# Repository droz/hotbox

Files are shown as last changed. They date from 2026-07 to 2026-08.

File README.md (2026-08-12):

# Baked and Happy Hot-Box

Solar oven project with motorized mirrors, a Raspberry Pi supervisor, and two separate simulation stacks.

## System Overview

The oven body keeps its original controller panel, but the heating element relay is repurposed as a demand signal for the solar concentrator. When the oven wants power, a set of motorized mirrors aims reflected sunlight at the absorber on the back of the oven. When the oven does not want power, the mirrors park toward a safe sky target.

Each mirror is a faceted spherical mirror mounted on an alt-azimuth mount:

- angles use the astronomical convention: elevation `0°` = horizon / `90°` = zenith;
  azimuth `0°` = north, `90°` = east (clockwise from north)
- body → world rotation is `R_z(−az) @ R_x(el − 90°)` (identity / face-up at `(0, 90)`)
- each mirror has a local mount frame `Fm`
- the oven absorber center `O` is the origin of the world frame `Fw`

The world frame used by the software is:

- `X`: east
- `Y`: north
- `Z`: up

## Hardware Architecture

### Mirror Controller

Each mirror has its own Arduino Nano ESP32 board. The board controls:

- two brushed DC motors through DRV8871 drivers
- one quadrature encoder per motor
- one hall sensor per axis for homing/reference

The mirror controller communicates with the main controller in two ways:

- **CAN bus** for normal operation in the final system
- **USB serial** for debugging, bench bring-up, and testing without the CAN bus

Pin mappings are documented in `electrical/pinouts.txt`.

### Main Controller

The main controller is a Raspberry Pi with:

- an MCP2515 CAN hat on SPI
- a GPIO input that reads the oven's original heat-demand relay state
- a GY-NEO6MV2 NEO-6M GPS module for time and location

The Pi:

- computes the sun location from GPS data using `pvlib`
- converts the sun position into a world-frame vector
- computes where each mirror should point
- sends commands to each mirror node
- serves a small web UI for monitoring, manual control, and calibration

## Software Architecture

## `firmware/`

Arduino-first mirror-node firmware with the same high-level command set over CAN and USB serial.

Responsibilities:

- homing from hall sensors
- encoder counting
- motor PWM and direction control
- closed-loop axis tracking with acceleration limiting
- stall/fault reporting
- mirror status reporting

The current scaffold is intentionally thin and is meant to grow around proven libraries rather than custom low-level drivers.

## `controller/`

Python package for the Raspberry Pi runtime.

Responsibilities:

- GPS NMEA parsing for the NEO-6M (with site fallback when no fix)
- sun vector calculation with `pvlib`
- mirror discovery and supervision
- transport abstraction for `CAN` and `USB serial`
- target generation for active tracking or safe parking
- calibration file loading/saving
- FastAPI server plus a lightweight Three.js web page
- current pose vs commanded target geometry overlay in the web UI

Current module split:

- `hotbox_controller/gps.py`
- `hotbox_controller/sun.py`
- `hotbox_controller/scene.py`
- `hotbox_controller/transport.py`
- `hotbox_controller/mirror_fleet.py`
- `hotbox_controller/tracking.py`
- `hotbox_controller/calibration.py`
- `hotbox_controller/app.py`

## `sim_in_the_loop/`

Fast SITL for controller and firmware development: real firmware C-in-the-loop
(`axis`/`protocol` as per-node native libraries) plus a Python plant
(motors/encoders/halls) and the same JSON protocol as USB.

Purpose:

- run the same control code as the ESP32 on a laptop
- simulate motors, encoders, and hall sensors
- visualize simplified aiming geometry
- debug calibration and mirror pointing

This simulation intentionally uses:

- one representative ray per facet center
- no occlusion model
- simulator-owned "true" calibration values

Its goal is software integration and geometry debugging, not high-fidelity thermal/power prediction.

## `sim_full_raytrace/`

Renamed version of the original exploratory optical simulator. This remains the place for:

- many-ray optical studies
- occlusion effects
- delivered power estimation
- geometry experiments that need more fidelity than the in-the-loop simulator

Plant geometry (site, absorber, facet grid, fleet mounts) is loaded from `config/system.yaml`
via `hotbox_shared`, same as the controller and SITL.
## Tracking And Control Flow

1. The Pi boots and starts the controller service.
2. GPS provides current UTC time and site coordinates.
3. The controller loads saved calibration data.
4. Mirror nodes are discovered over the configured transport (`CAN` or `USB serial`).
5. Mirrors are homed if needed.
6. The controller computes the current sun vector from `pvlib`.
7. If the oven requests heat, mirrors track the absorber.
8. If the oven does not request heat, mirrors park to a safe sky direction.

## Calibration

Per mirror, the known geometric values are:

- distance `|OA_n|`
- mirror offset `d = |A_nM_n|`
- mirror focal length

The unknowns to calibrate are:

- bearing of `OA_n` relative to north
- height difference between `O` and `A_n`
- homed azimuth offset
- homed elevation offset

Calibration flow:

1. Home the mirror.
2. Jog until the center facet points directly at `O`.
3. Jog until the sun is focused on `O`.
4. Save the solved calibration values to disk.

The controller package already includes calibration file load/save support. The numerical solve and guided routine still need to be filled out in more detail as hardware data becomes available.

## Library Strategy

Prefer existing libraries where they fit:

- firmware: `ESP32Encoder`, `PID`, PlatformIO-managed deps; CAN via ESP32-S3 TWAI
- controller: `pvlib`, `python-can`, `pyserial`, `FastAPI`, `numpy`, `scipy`, `PyYAML`
- UI: `Three.js`

Custom code should stay focused on:

- project-specific geometry
- transport-neutral mirror protocol
- calibration math
- plant models for SITL (encoders/halls/PWM), with firmware C-in-the-loop

## Repository Layout

- `config/` — shared plant constants (`system.yaml`) and calibration files
- `shared/` — Python package that loads those shared constants
- `controller/` — Raspberry Pi controller package
- `electrical/` — pinouts and electronics notes
- `firmware/` — mirror-node firmware
- `mechanical/` — CAD and printable parts
- `sim_full_raytrace/` — high-fidelity optical simulator
- `sim_in_the_loop/` — fast integration simulator

## Shared plant constants

Geometry and plant constants live in one place:

```text
config/system.yaml
```

Loaded by:

```python
from hotbox_shared import load_system_constants
system = load_system_constants()
```

This includes:

- default site lat/lon/altitude
- absorber size and height
- mirror facet grid (`nx`/`ny`), tile size, pitch
- mount offset `d`, sphere radius / focal length
- fleet mount bearings (relative to oven/absorber normal) and `|OA|` design values

Generate the firmware C header from the same file:

```bash
cd shared && uv run hotbox-gen-firmware-geometry
```

That writes `firmware/include/hotbox_geometry.h`.

## Development

Python packages use `uv`.

Examples:

```bash
cd controller && uv run hotbox-controller
cd sim_in_the_loop && uv run hotbox-sim-in-the-loop
# then open http://127.0.0.1:8000/
cd sim_full_raytrace && uv run hotbox-sim-full-raytrace
```

`hotbox-sim-in-the-loop` starts a continuous simulation and the controller web UI.
Use `--batch-seconds N` for a short headless run.

### Transports

The controller supports three mirror transports:

- `usb` — JSON lines over USB serial (`pyserial`); default for bench bring-up
- `can` — compact binary frames over SocketCAN (`python-can`); typical on a Pi in the field
- `sim` — in-process firmware-CIL mirror nodes (used by `sim_in_the_loop/`)

Override transport with `HOTBOX_TRANSPORT=usb|can|sim` (default `usb`).

USB port mapping:

- **One** Arduino Nano ESP32 plugged in → auto-discovered by USB VID/PID (`2341:0070`) and mapped to **node 0**
- **Multiple** boards → set an explicit map (VID/PID alone cannot tell which board is which node):

```bash
export HOTBOX_USB_PORTS='0:/dev/cu.usbmodem1101,1:/dev/ttyACM1'
```

Paths look like `/dev/cu.usbmodem*` on macOS and `/dev/ttyACM*` on Linux.

### Flash firmware and test a real board (not simulation)

Works the same on a Mac (USB bench) or a Raspberry Pi.

1. **Plug in** the Nano ESP32 over USB. Unplug other Nano ESP32 boards first for single-board bring-up.

2. **Flash** firmware for the matching node id (single-board auto-discovery expects **0**):

```bash
cd firmware
uv run hotbox-firmware-upload --node-id 0
# optional: --port /dev/cu.usbmodem1101   # or /dev/ttyACM0 on Linux
```

Upload always builds that node first. For a second board, flash `--node-id 1`, leave both plugged in, and set `HOTBOX_USB_PORTS` as above.

3. **Start the controller** against real USB (not `sim_in_the_loop`):

```bash
cd controller
# optional: export HOTBOX_TRANSPORT=usb
# optional: export HOTBOX_USB_PORTS='0:/dev/ttyACM0'
uv run hotbox-controller
```

Open [http://127.0.0.1:8000/](http://127.0.0.1:8000/). You should see mirror **M0** with current pose (blue) and commanded target (yellow).

4. **Smoke-test from the UI**

- Select the **M0** tab.
- Put the mirror in **Raw** so Track/Park do not overwrite your wire commands.
- Expand **Protocol** → send `get_status` and confirm a status reply in the log.
- Prefer **Home** once (or Protocol `home`) before commanding large moves.
- Try Protocol `set_target` with small angles, or switch to **Jog** and nudge with the stick.
- Use **Park** / **Track** only when you intend the supervisor to drive targets (Track also follows heat-demand / sun logic).

On a Pi with CAN instead of USB serial:

```bash
export HOTBOX_TRANSPORT=can
# nodes are addressed by CAN id; plug USB only if you still need it for programming
cd controller && uv run hotbox-controller
```

Firmware build/upload helpers:

```bash
cd firmware
uv run hotbox-firmware-build --node-id 0
uv run hotbox-firmware-upload --node-id 1 --port /dev/ttyACM0
```

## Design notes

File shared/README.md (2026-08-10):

# hotbox-shared

Shared plant constants and mirror pointing geometry for:

- `controller/`
- `sim_in_the_loop/`
- `sim_full_raytrace/`
- firmware (via generated C header)

## Source of truth

Edit the repo-level file:

```text
config/system.yaml
```

Then load it in Python:

```python
from hotbox_shared import load_system_constants

system = load_system_constants()
print(system.default_site.latitude_deg)
print(system.default_site.timezone_id)
print(system.absorber.center_height_m)
print(system.mirror.grid_nx, system.mirror.grid_ny)
print(system.control.solve_for_mount_offset)
```

## Site time and location

Never use the computer's local timezone. Civil-day work and plots use
`default_site.timezone_id` from `config/system.yaml`. Live time prefers GPS UTC when
available, otherwise `utc_now()`.

```python
from hotbox_shared import (
    SitePose,
    as_site_local,
    ensure_utc,
    format_site_local,
    load_system_constants,
    local_times_sunrise_to_sunset,
    site_local_datetime,
    utc_now,
)

site = SitePose.from_constants(load_system_constants().default_site)
when = site_local_datetime(site, 2026, 9, 7, 14, 0, 0)  # 14:00 at the plant
times, sunrise, sunset = local_times_sunrise_to_sunset(
    site, year=2026, month=9, day=7, step_minutes=20
)
print(format_site_local(when, site))
print(ensure_utc(when))  # physics / pvlib
```

| Symbol | Role |
|---|---|
| `SitePose` | lat/lon/alt + IANA `timezone_id` |
| `site_local_datetime` | Build aware civil time at the site |
| `as_site_local` / `format_site_local` | Convert / print in site TZ |
| `ensure_utc` | Aware → UTC; **raises** on naive (no host-TZ guess) |
| `utc_now` | Host clock as UTC (fallback when GPS unavailable) |
| `local_times_sunrise_to_sunset` | Site-local samples from SPA sunrise→sunset |

## Mirror pointing

Both the live controller and the full raytrace simulation use the same aiming solver in
`hotbox_shared.aiming`. This is the single source of truth for deciding where each alt-az
mount should point.

### Quick start

```python
import numpy as np
from hotbox_shared import MirrorGridSpec, evaluate_center_ray, solve_tracking_for_grid

grid = MirrorGridSpec(
    grid_nx=3,
    grid_ny=5,
    pitch_m=0.26035,
    radius_of_curvature_m=5.5,
    mount_offset_d_m=0.1,
)

# Unit vector from the sun toward the plant (ENU world frame).
sun_toward_scene = -sun_vector_from_pvlib
mount = np.array([0.0, 2.5, 1.0])
target = np.array([0.0, 0.0, 1.0])  # absorber center

angles = solve_tracking_for_grid(
    sun_direction_toward_scene=sun_toward_scene,
    mount_world=mount,
    target_world=target,
    grid=grid,
    solve_for_mount_offset=True,  # also controlled by control.solve_for_mount_offset in YAML
)

# Forward model: where does the center ray go?
ray = evaluate_center_ray(
    sun_direction_toward_scene=sun_toward_scene,
    mount_world=mount,
    azimuth_deg=angles.azimuth_deg,
    elevation_deg=angles.elevation_deg,
    mount_offset_d_m=grid.mount_offset_d_m,
    pivot_facet_normal_body=grid.pivot_normal_body(),
)
print(angles.azimuth_deg, angles.elevation_deg)
print("miss_m", ray.miss_m(target))
print("impact on absorber plane", ray.impact_on_plane(target, np.array([0.0, 1.0, 0.0])))
```

### Algorithm

1. **Bisector seed** — flat heliostat at the mount pivot (ignores `mount_offset_d_m`).
2. **Offset refine** (optional) — `scipy.optimize.least_squares` nudges `(az, el)` so the
   **center facet** reflected ray aims at the absorber. Forward model:
   `evaluate_center_ray`.

Toggle refinement with `control.solve_for_mount_offset` in `config/system.yaml`
(set `false` to keep the bisector seed only).

### API reference

| Symbol | Role |
|---|---|
| `solve_tracking` / `solve_tracking_for_grid` | **Primary** aiming API (seed + optional refine) |
| `evaluate_center_ray` / `CenterRay` | Forward geometry: facet pose, reflected ray, miss / plane impact |
| `solve_bisector_tracking` | Closed-form pivot bisector seed only |
| `MountAngles` | Result: `azimuth_deg`, `elevation_deg` |
| `MirrorGridSpec` | Facet grid + `mount_offset_d_m` |
| `pivot_facet_center_world` | `mount + R @ (0,0,d)` |
| `mount_rotation_matrix` | Body → world rotation `R_z(−az) @ R_x(el − 90°)` (astro az/el) |

### Frames

Right-handed ENU world frame: **+x east**, **+y north**, **+z up**. Mount body frame
matches world at `(azimuth, elevation) = (0, 90)`. Center facet at `(0, 0, mount_offset_d_m)`
in body coordinates.

## Firmware header

Generate a C header from the same YAML:

```bash
cd shared
uv run hotbox-gen-firmware-geometry
```

This writes `firmware/include/hotbox_geometry.h`.

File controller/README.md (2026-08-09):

# hotbox controller

Main Python runtime for the Raspberry Pi:

- reads GPS time/location
- computes the sun vector with `pvlib`
- supervises mirror nodes over CAN or USB serial
- manages calibration files
- serves a small FastAPI + Three.js UI

Run locally with:

```bash
uv run hotbox-controller
```

Then open `http://127.0.0.1:8000/`.

**USB bring-up:** with a single Arduino Nano ESP32 connected, the board is auto-discovered
(VID/PID `2341:0070`) and mapped to node 0. For multiple boards, set
`HOTBOX_USB_PORTS=0:/dev/...,1:/dev/...`. See the root README section
“Flash firmware and test a real board”.

**Simulation:** use `sim_in_the_loop` (`HOTBOX_TRANSPORT=sim`) instead of this package alone.

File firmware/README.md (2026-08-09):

# hotbox firmware

Arduino-first mirror controller for the Arduino Nano ESP32.

Goals:

- same high-level command protocol over CAN and USB serial
- brushed DC motor control through DRV8871
- quadrature encoder + hall homing
- host-shim friendly structure for simulation

Build / flash with `uv` (installs PlatformIO into this package env).
Each mirror has its own build env, and upload always builds that node first:

```bash
cd firmware
uv run hotbox-firmware-build --node-id 0
uv run hotbox-firmware-upload --node-id 1
# optional: uv run hotbox-firmware-upload --node-id 1 --port /dev/cu.usbmodem1101
```

`--node-id` must be `0`, `1`, or `2` (matches `config/system.yaml` mounts).

Or call PlatformIO directly:

```bash
pio run -e nano_esp32_node0
pio run -t upload -e nano_esp32_node1
```

The firmware implements:

- brushed-axis control with `ESP32Encoder` + `PID_v1`
- hall-sensor homing
- position servo (`set_target`); host integrates jog rates into targets
- status modes: `idle` | `homing` | `position` | `fault`
- USB serial JSON protocol and ESP32-S3 TWAI (CAN) binary protocol
- TWAI soft-fails without a transceiver so USB bench bring-up still works

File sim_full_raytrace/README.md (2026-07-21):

# hotbox full raytrace sim

Vectorized optical raytrace for the Hot-Box flat-mirror solar oven (rigid facet grid on
alt–az mounts). Plant geometry comes from the shared repo config; sim-only knobs stay in
`src/main.py`.

## Shared plant constants

Edit:

```text
config/system.yaml
```

Loaded via:

```python
from hotbox_shared import load_system_constants
```

This drives site lat/lon/altitude, absorber size, facet grid, sphere radius, mount offset
`d`, and fleet mount bearings relative to the oven/absorber normal (same source as controller
and SITL).

## Run with uv

```bash
uv run hotbox-sim-full-raytrace
```

The script prints power statistics and opens Plotly figures:

- 3D scene (ground, absorber, mirror tiles, incoming and reflected rays)
- Spot pattern on absorber plane
- Delivered power vs local time (sunrise–sunset on the configured day)

Sim-only options (samples, day-curve dates, visualization density) live in `src/main.py`.
Incoming ray power uses **pvlib** clear-sky DNI (Ineichen) at the simulation time for the
configured site.

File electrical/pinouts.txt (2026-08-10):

MOTOR CONNECTOR
---------------

NAME         | COLOR  | CIRCULAR_PIN  | JST_PIN 
-------------+--------+---------------+---------
MOTOR+       | RED    | 1             | 2-1  
MOTOR-       | BLACK  | 2             | 2-2
ENC/HALL_GND | GREY   | 7             | 6-1
ENC_VCC      | BLUE   | 6             | 6-2
ENC_A        | YELLOW | 3             | 6-4
ENC_B        | WHITE  | 4             | 6-5
HALL_VCC     | BROWN  | 8             | 6-3
HALL_OUT     | GREEN  | 5             | 6-6

INTERFACE CONNECTOR
-------------------

NAME         | COLOR  | JST_PIN
-------------+--------+----------
GND          | BLACK  | 1
VCC_12V      | RED    | 2
CAN_H        | YELLOW | 3
CAN_L        | GREEN  | 4

Firmware pin *roles* (including encoder A/B sense) live in config/system.yaml
under `pins:` and are baked into firmware via `uv run hotbox-gen-firmware-geometry`.
Swap elevation_enc_a/b or azimuth_enc_a/b there to invert quadrature direction.

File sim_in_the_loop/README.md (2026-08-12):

# hotbox sim in the loop

Controller + **firmware C-in-the-loop** (real `axis`/`protocol` C++) + Python plant,
talking the same JSON protocol as USB, with a live web UI.

## Prerequisites

Native CIL libraries (autobuild on first run, or explicitly):

```bash
cd firmware/native && make
```

This produces `libfirmware_cil_node{0,1,2}.dylib` (macOS) or `.so` (Linux) — one
library per mirror so multi-node sims do not share HAL state.

## Live interactive mode (default)

```bash
uv run hotbox-sim-in-the-loop
```

Then open:

```text
http://127.0.0.1:8000/
```

Or from another device on the same network (server binds to all interfaces by default):

```text
http://<your-lan-ip>:8000/
```

The page shows:

- current reported pose (blue)
- firmware position setpoint / target (yellow)
- GPS / sun / mirror status
- Home, Park, Auto, and jog controls

Optional flags:

```bash
uv run hotbox-sim-in-the-loop --host 127.0.0.1 --port 8000
```

Use `--host 127.0.0.1` if you want localhost-only access.

## Headless batch mode

Useful for smoke tests:

```bash
uv run hotbox-sim-in-the-loop --batch-seconds 3
```

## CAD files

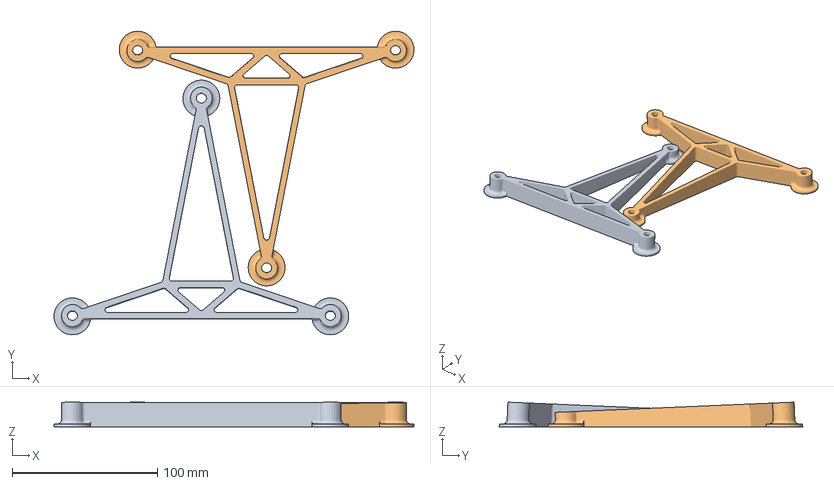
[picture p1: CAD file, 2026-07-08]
mechanical/3D Printed Mirror Support_0,1.3mf
248.2 x 209.2 x 17.1 mm

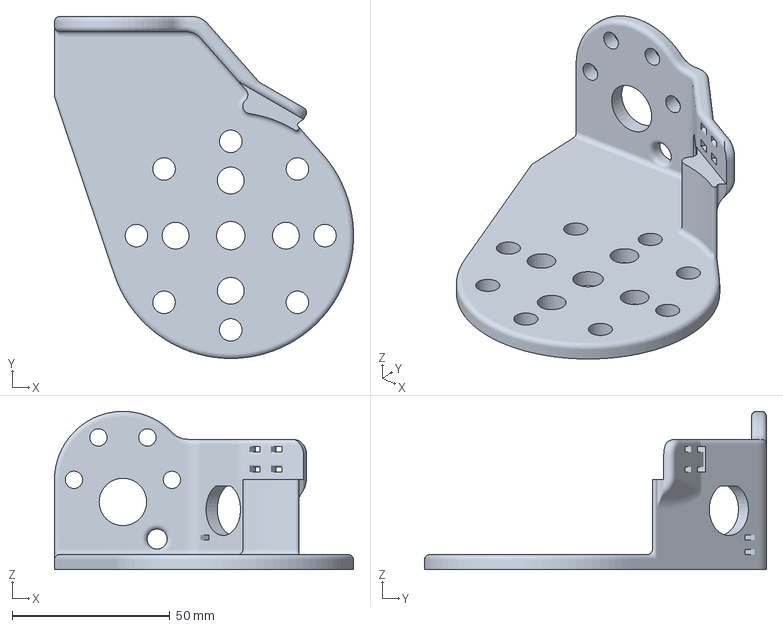
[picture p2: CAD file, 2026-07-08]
mechanical/3D Printed Motor Support.3mf
94.7 x 108.3 x 50.1 mm

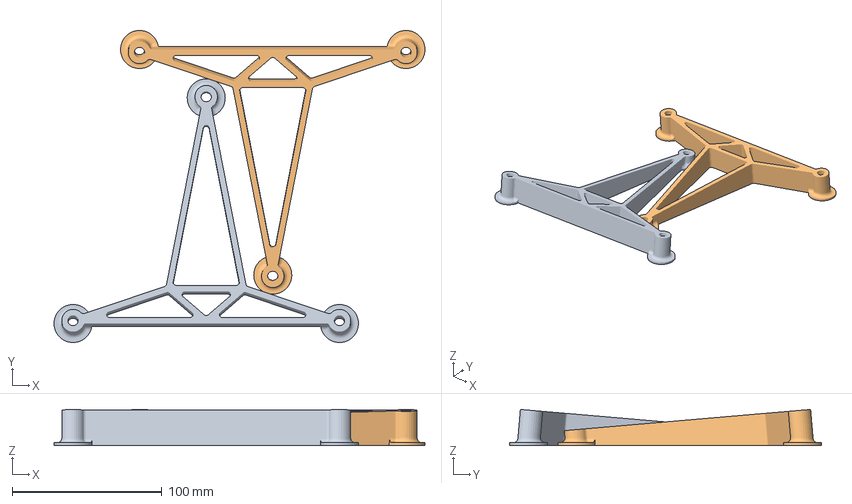
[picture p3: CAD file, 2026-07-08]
mechanical/3D Printed Mirror Support_0,2.3mf
247.6 x 208.2 x 24.1 mm

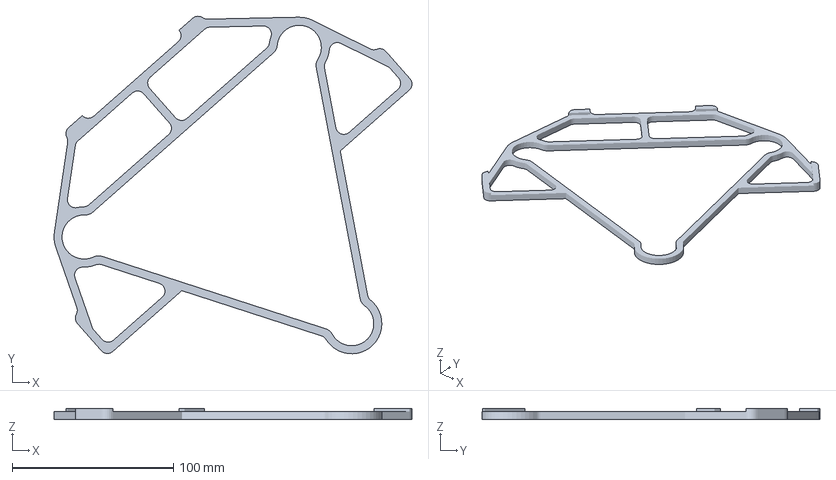
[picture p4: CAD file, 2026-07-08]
mechanical/3D Printed Mirror Support_jig.3mf
222.0 x 209.3 x 7.00 mm

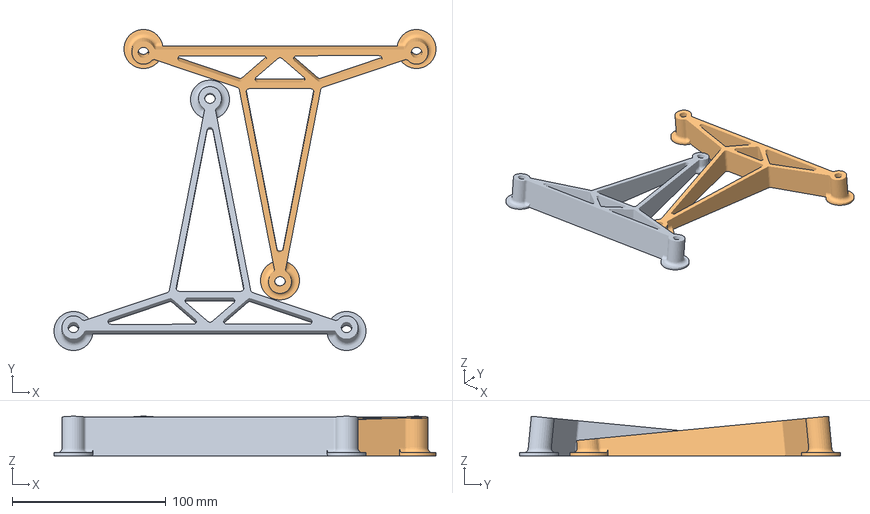
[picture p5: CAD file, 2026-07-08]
mechanical/3D Printed Mirror Support_1,2.3mf
248.8 x 209.0 x 25.8 mm

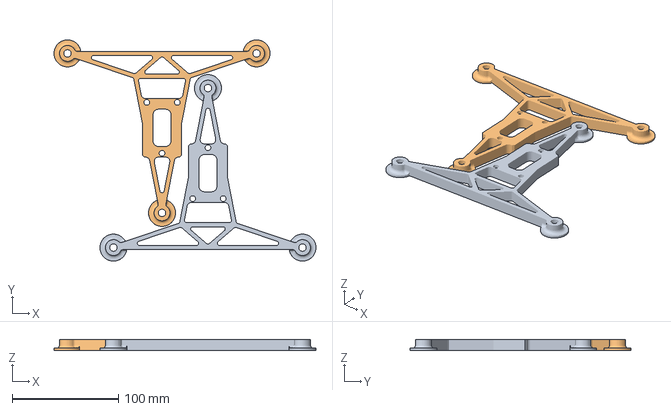
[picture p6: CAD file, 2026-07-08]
mechanical/3D Printed Mirror Support_0,0.3mf
246.4 x 208.0 x 10.0 mm

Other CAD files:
mechanical/3D Printed Mirror Support_1,1.3mf

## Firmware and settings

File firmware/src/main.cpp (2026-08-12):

#include <Arduino.h>

#include "axis.h"
#include "can_bus.h"
#include "config.h"
#include "protocol.h"

#include <cstring>

hotbox::MirrorMount g_mount;
hotbox::ProtocolHandler g_protocol(&g_mount);
hotbox::CanBus g_can(&g_protocol);

namespace {

constexpr size_t kSerialLineMax = 512;
constexpr int kSerialBytesPerLoop = 96;

}  // namespace

void setup() {
  Serial.begin(115200);
  // USB CDC: wait briefly for the host to open the port after reset-on-open.
  const unsigned long wait_start = millis();
  while (!Serial && (millis() - wait_start) < 3000) {
    delay(10);
  }
  delay(200);
  g_mount.begin();
  g_can.begin();  // Soft-fails without a transceiver; USB still works.
  Serial.print("{\"hotbox\":\"mirror_firmware\",\"transport\":\"usb\",\"node_id\":");
  Serial.print(HOTBOX_NODE_ID);
  Serial.print(",\"az_hall\":");
  Serial.print(g_mount.azimuthHallTriggered() ? "true" : "false");
  Serial.print(",\"el_hall\":");
  Serial.print(g_mount.elevationHallTriggered() ? "true" : "false");
  Serial.println("}");
}

void loop() {
  static char line_buf[kSerialLineMax];
  static size_t line_len = 0;
  static unsigned long last_update_ms = 0;
  static bool was_homing = false;
  const unsigned long now_ms = millis();
  const float dt_s = (now_ms - last_update_ms) / 1000.0f;

  // Control first: never let USB RX/TX starve the motor loop (runaway PWM).
  if (last_update_ms == 0 || dt_s >= hotbox::kControlPeriodS) {
    const float step_dt = (last_update_ms == 0) ? hotbox::kControlPeriodS : dt_s;
    g_mount.update(step_dt);
    last_update_ms = now_ms;

    const bool homing = std::strcmp(g_mount.modeText(), "homing") == 0;
    if (was_homing && !homing) {
      // Homing finished (success → idle/homed, or fault). Push status so the
      // host does not have to wait for the next poll.
      g_protocol.emitStatus();
    }
    was_homing = homing;
  }

  int budget = kSerialBytesPerLoop;
  while (budget-- > 0 && Serial.available() > 0) {
    const char ch = static_cast<char>(Serial.read());
    if (ch == '\n' || ch == '\r') {
      if (line_len > 0) {
        line_buf[line_len] = '\0';
        g_protocol.handleLine(String(line_buf));
        line_len = 0;
      }
    } else if (line_len + 1 < kSerialLineMax) {
      line_buf[line_len++] = ch;
    } else {
      // Overflow / garbage: drop the line rather than grow forever.
      line_len = 0;
    }
  }

  g_can.poll();
}

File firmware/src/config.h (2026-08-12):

#pragma once

#include <Arduino.h>
#include "hotbox_geometry.h"

namespace hotbox {

// ── Pin assignments (from config/system.yaml via hotbox_geometry.h) ───────────
constexpr int kCanTxPin = HOTBOX_PIN_CAN_TX;
constexpr int kCanRxPin = HOTBOX_PIN_CAN_RX;

constexpr int kVertMotorP = HOTBOX_PIN_ELEVATION_MOTOR_P;
constexpr int kVertMotorM = HOTBOX_PIN_ELEVATION_MOTOR_M;
constexpr int kVertEncA = HOTBOX_PIN_ELEVATION_ENC_A;
constexpr int kVertEncB = HOTBOX_PIN_ELEVATION_ENC_B;
constexpr int kVertHall = HOTBOX_PIN_ELEVATION_HALL;

constexpr int kHorizMotorP = HOTBOX_PIN_AZIMUTH_MOTOR_P;
constexpr int kHorizMotorM = HOTBOX_PIN_AZIMUTH_MOTOR_M;
constexpr int kHorizEncA = HOTBOX_PIN_AZIMUTH_ENC_A;
constexpr int kHorizEncB = HOTBOX_PIN_AZIMUTH_ENC_B;
constexpr int kHorizHall = HOTBOX_PIN_AZIMUTH_HALL;

// H-bridge PWM carrier (Arduino-ESP32 default is 1 kHz; 20 kHz is above hearing).
constexpr int kMotorPwmHz = HOTBOX_MOTOR_PWM_HZ;

#ifndef HOTBOX_NODE_ID
#define HOTBOX_NODE_ID 0
#endif

// ESP32Encoder / TWAI take Espressif GPIO numbers. On Nano ESP32 the Arduino
// D# labels are remapped (D5 → GPIO 8, etc.), so convert before driving
// peripherals that bypass the Arduino pin API.
#if defined(NATIVE_CIL)
inline int pinToGpio(int arduino_pin) { return arduino_pin; }
#else
inline int pinToGpio(int arduino_pin) {
  return static_cast<int>(digitalPinToGPIONumber(static_cast<int8_t>(arduino_pin)));
}
#endif

// ── Actuator constants (generated from config/system.yaml) ───────────────────
// Regenerate with: uv run hotbox-gen-firmware-geometry
constexpr float kControlPeriodS         = HOTBOX_CONTROL_PERIOD_S;
constexpr float kMaxVelocityDegS        = HOTBOX_MAX_VELOCITY_DEG_S;
constexpr float kMaxAccelDegS2          = HOTBOX_MAX_ACCEL_DEG_S2;
constexpr float kHomingVelocityDegS     = HOTBOX_HOMING_VELOCITY_DEG_S;
constexpr float kHomingClearDistanceDeg = HOTBOX_HOMING_CLEAR_DISTANCE_DEG;
/** Post-home azimuth relative to oven-facing (same frame as kAzimuthMin/MaxDeg). */
constexpr float kHomeAzimuthDeg         = HOTBOX_HOME_AZIMUTH_DEG;
/** Post-home elevation absolute (0° = horizon, 90° = zenith). */
constexpr float kHomeElevationDeg       = HOTBOX_HOME_ELEVATION_DEG;
/** Encoder-space seek sign for azimuth/elevation (+1 or -1). Leave uses opposite. */
constexpr float kHomingDirectionAzimuth =
    (HOTBOX_HOMING_DIRECTION_AZIMUTH < 0) ? -1.0f : 1.0f;
constexpr float kHomingDirectionElevation =
    (HOTBOX_HOMING_DIRECTION_ELEVATION < 0) ? -1.0f : 1.0f;
/** Expected hall magnet window width [°] (edge-to-edge). */
constexpr float kHallWindowWidthDeg = HOTBOX_HALL_WINDOW_WIDTH_DEG;
/** Allowed |measured − expected| hall width after home [°]. */
constexpr float kHallWindowToleranceDeg = HOTBOX_HALL_WINDOW_TOLERANCE_DEG;
constexpr float kTicksPerDegree         = HOTBOX_TICKS_PER_DEGREE;
constexpr float kPidKp                  = HOTBOX_PID_KP;
constexpr float kPidKi                  = HOTBOX_PID_KI;
constexpr float kPidKd                  = HOTBOX_PID_KD;
constexpr float kPidVelocityKp          = HOTBOX_PID_VELOCITY_KP;
constexpr float kPidVelocityKi          = HOTBOX_PID_VELOCITY_KI;
constexpr float kPidVelocityKd          = HOTBOX_PID_VELOCITY_KD;
constexpr float kPidIntegralLimit       = HOTBOX_PID_INTEGRAL_LIMIT;
constexpr float kPwmDeadband            = HOTBOX_PWM_DEADBAND;
constexpr float kPositionDeadbandDeg    = HOTBOX_POSITION_DEADBAND_DEG;
constexpr float kStallVelocityThreshDegS = HOTBOX_STALL_VELOCITY_THRESHOLD_DEG_S;
constexpr float kStallTimeoutS          = HOTBOX_STALL_TIMEOUT_S;
/** If no set_velocity refresh arrives while in Velocity mode, coast (host lost / USB stall). */
constexpr float kVelocityCommandTimeoutS = 0.30f;

// Joint limits (from config/system.yaml). Azimuth is joint-relative to oven-facing.
constexpr float kElevationMinDeg = HOTBOX_ELEVATION_MIN_DEG;
constexpr float kElevationMaxDeg = HOTBOX_ELEVATION_MAX_DEG;
constexpr float kAzimuthMinDeg = HOTBOX_AZIMUTH_MIN_DEG;
constexpr float kAzimuthMaxDeg = HOTBOX_AZIMUTH_MAX_DEG;

}  // namespace hotbox

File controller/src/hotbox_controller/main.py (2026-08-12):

from __future__ import annotations

import uvicorn

from .app import ControllerApplication


def main() -> None:
    app = ControllerApplication()
    app.startup()
    # Closed-loop Track/Park (and jog rate streaming) need a periodic tick.
    # SITL runs control_tick from its physics thread instead.
    app.start_control_loop()
    try:
        uvicorn.run(app.fastapi, host=app.config.web_host, port=app.config.web_port)
    finally:
        app.stop_control_loop()


if __name__ == "__main__":
    main()

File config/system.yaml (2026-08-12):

# Hot-Box plant / geometry constants
# Shared by controller, sim_in_the_loop, sim_full_raytrace, and (via generated header) firmware.
# Edit this file rather than hardcoding values in Python or C++.

default_site:
  # Diemoz, France
#  latitude_deg: 45.5885
#  longitude_deg: 5.0904
#  altitude_m: 380.0
#  timezone_id: Europe/Paris
  # Berkeley, California
  latitude_deg: 37.8716
  longitude_deg: -122.2585
  altitude_m: 186.0
  timezone_id: America/Los_Angeles
#  # Gerlach, Nevada
#  latitude_deg: 40.6518
#  longitude_deg: -119.3562
#  altitude_m: 1200.0
#  timezone_id: America/Los_Angeles

# Absorber center O is the world origin XY, at center_height_m on Z.
absorber:
  width_m: 0.40
  height_m: 0.40
  center_height_m: 1.0
  # Oven / absorber face normal in the horizontal plane.
  # 0° = +X east, 90° = +Y north. Changing this rotates the whole plant.
  normal_angle_from_x_deg: 90.0

mirror:
  # Faceted spherical assembly on one alt-az mount
  grid_nx: 3
  grid_ny: 5
  tile_side_m: 0.254
  pitch_m: 0.26035            # tile_side + 0.0254/4
  mount_offset_d_m: 0.1       # |An Mn| along mirror-frame Z (offset between mirrror surface andmount rotation point)
  radius_of_curvature_m: 5.5  # design sphere radius (paraxial focal length ≈ R/2)
  default_oa_distance_m: 2.5  # |O An| horizontal design distance
  default_mount_height_m: 1.0 # An height above ground (world Z)

fleet:
  assembly_count: 3
  # Center-to-center spacing between assemblies along an arc / line [m]
  assembly_spacing_m: 1.0
  # Design layout: mounts on a horizontal arc in front of the oven back.
  # bearing_deg is relative to absorber.normal_angle_from_x_deg:
  #   0 = straight out along the oven normal; +CCW about +Z (up).
  mounts:
    - node_id: 0
      bearing_deg: 0.0
      oa_distance_m: 2.5
      mount_height_m: 1.0
    - node_id: 1
      bearing_deg: -30.0
      oa_distance_m: 2.5
      mount_height_m: 1.0
    - node_id: 2
      bearing_deg: 30.0
      oa_distance_m: 2.5
      mount_height_m: 1.0

control:
  # Face-up stow: elevation 90° (zenith). Azimuth is filled per-node with oven-facing
  # at runtime so each mount parks with relative az = 0 (center of travel).
  # Elevation is astronomical: 0° = horizon, 90° = zenith.
  # Azimuth is astronomical: 0° = north, 90° = east (CW from north).
  safe_park_azimuth_deg: 0.0
  safe_park_elevation_deg: 90.0
  # When the oven is not requesting heat, Track mirrors aim this far above the absorber
  # center (world +Z) instead of focusing on the absorber.
  idle_aim_height_above_absorber_m: 2.0
  # When true, solve for mount_offset_d_m via least squares after the bisector seed.
  # Set false to use the pivot-bisector seed only (useful for A/B testing).
  solve_for_mount_offset: true
  # Physical mount travel. Azimuth is relative to oven-facing (0 = aim at absorber at el→0).
  elevation_min_deg: 0.0
  elevation_max_deg: 90.0
  azimuth_min_deg: -100.0
  azimuth_max_deg: 100.0

actuator:
  # ── Encoder / gearbox ────────────────────────────────────────────────────────
  # Encoder is on the motor shaft BEFORE both reduction stages.
  # ticks_per_degree = (encoder_ppr × 4) × motor_gear_ratio × worm_gear_ratio / 360
  encoder_ppr: 16              # Pulses per revolution of the motor shaft (single-channel edges)
  motor_gear_ratio: 70.0       # Motor gearbox (motor shaft → intermediate)
  worm_gear_ratio: 120.0       # Mount worm drive (intermediate → output / mount shaft)
  # Overall gear_ratio = motor_gear_ratio × worm_gear_ratio (derived in code)

  # ── Velocity limits ───────────────────────────────────────────────────────────
  max_velocity_deg_s: 5.0    # Maximum output-shaft speed [°/s]
  max_accel_deg_s2: 10.0     # Maximum output-shaft acceleration [°/s²] (firmware ramp limiter)
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

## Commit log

2026-03-21 Added estimation of power through the day
2026-03-21 refactored cylinder intersection
2026-07-08 Added 3D printing files and connector pinouts
    [3D Printed Mirror Support_0,0.3mf, 3D Printed Mirror Support_0,1.3mf, 3D Printed Mirror Support_0,2.3mf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]
2026-07-17 Added Arduino pinout
2026-07-21 Fixed default mirror angle
    [system.yaml]
2026-07-21 Fixed mirror target angle bug
    [app.py, calibration_solver.py, geometry.py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]
2026-07-24 Added mount offset compensation
2026-07-29 Moved all motor and motion constants to system.yaml
2026-07-29 Added true software in the loop simulation (compiles and links the arduino code)
2026-07-29 Fixed C++ to match python controller model
    [axis.cpp, firmware_cil.cpp]
2026-08-03 Fixed limits and UI improvements
    [app.py, axis.cpp, config.h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]
2026-08-09 Fixed USB comms issues. First testing on hardware
    [app.py, axis.cpp, axis.h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]
2026-08-09 Fixed swapped el/az encoder pins
    [config.h, firmware_cil.cpp]
2026-08-09 Early PID tuning
2026-08-09 Some mor PID tuning
2026-08-10 flipped elevation to match standard astronomical convention
    [aiming.py, app.py, axis.cpp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]
2026-08-10 Simplified Home. Wired second axis. Fixed jog bug
    [app.py, axis.cpp, axis.h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]
2026-08-10 Added velocity controller
2026-08-10 Enforced homing
2026-08-11 Replaced motor controller with production intent one
    [system.yaml]
2026-08-11 Added specific constants for velocity PID
2026-08-12 Debugging features. Hardware cleaned (added filters on halls and encoders)
2026-08-12 fixed crash when jogging
    [axis.cpp, axis.h, config.h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]
2026-08-12 Made firnware only use local mount frame
